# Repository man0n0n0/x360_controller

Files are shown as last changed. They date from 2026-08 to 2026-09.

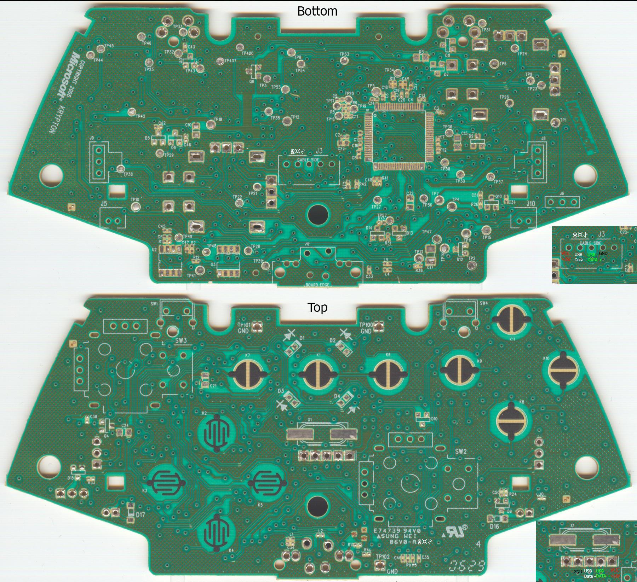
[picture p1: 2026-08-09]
hardware/F9HyhSM.jpg

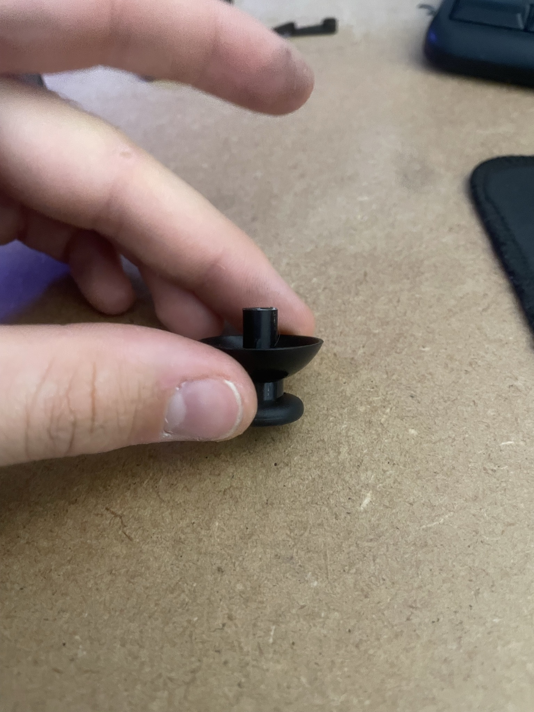
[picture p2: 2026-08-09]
img/IMG_0581.jpg

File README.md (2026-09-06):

# x360_controller

Manette Xbox 360 « jouée » par des servomoteurs : sticks, croix, boutons
colorés, gâchettes et moteurs de vibration sont actionnés mécaniquement
depuis un ESP32-C3, qui reçoit ses ordres d'un ordinateur hôte. Le but est
de rejouer une séquence de mouvements enregistrée, en synchronisation avec
une vidéo, pour une installation qui tourne sans opérateur.

## Contenu du dépôt

| Dossier / fichier | Contenu |
|---|---|
| `hardware/` | sources FreeCAD (`.FCStd`) et STL prêts à imprimer : coques, plaques, supports servo, mécanisme joystick PTFE, outil de perçage |
| `software/esp/` | firmware MicroPython de l'ESP32-C3 (`main_offline.py`, `main_wifi.py`, `boot.py`, `lib/servo.py`, `tools/servo_helper.py`) |
| `software/raspberrypi/` | maître Linux `control_host.py` (interface Tk + enregistreur) et séquence de test `button_test.json` |
| `software/raspberrypi/control_example/` | exemple d'installation : `record.py` (éditeur séquence/vidéo), `show.py` (lecture plein écran synchronisée), `caption.webm` |
| `img/` | photos de montage et schéma de câblage (`img/GPIO_servo`) |
| `FORMAT_JSON.md` | format des séquences |
| `notice.pdf` | notice d'assemblage illustrée |

## Architecture

```
hôte Linux  ──USB CDC (JSON par ligne)──▶  ESP32-C3  ──PWM/RMT──▶  servos + L298N
control_host.py / show.py                  main_offline.py
```

Deux firmwares au choix, couche de contrôle identique :

- **`main_offline.py`** (recommandé) — pilotage par USB série natif. Une
  ligne = un objet JSON. Pas de radio, latence limitée par le rafraîchissement
  servo à 50 Hz.
- **`main_wifi.py`** — point d'accès Wi-Fi + WebSocket et interface web
  embarquée. Pratique sans ordinateur, plus lent.

`boot.py` importe `main` : renommer ou adapter l'import selon le firmware
retenu. Appuyer sur **BOOT** au démarrage annule le lancement automatique et
donne accès au REPL (Thonny).

## Câblage (ESP32-C3 SuperMini)

| GPIO | Fonction |
|---|---|
| 0 / 1 | stick gauche X / Y |
| 2 / 3 | stick droit X / Y |
| 20 | croix directionnelle (4 directions) |
| 21 | boutons colorés (A/B/X/Y) |
| 4 / 10 | gâchettes LT / RT — pilotées par **RMT**, les 6 canaux LEDC étant déjà pris |
| 5 / 6 | L298N IN1 / IN2 — moteur de vibration A |
| 7 / 8 | L298N IN3 / IN4 — moteur B ; GPIO8 est aussi la LED intégrée |
| 9 | bouton BOOT — bascule le mode calibration |

Les cavaliers ENA/ENB du L298N restent en place (enable câblé HIGH) ; la
vitesse est modulée sur les broches IN.

## Mise en route

```bash
# hôte
pip install pyserial              # + pygame et ffmpeg pour control_example/
python3 software/raspberrypi/control_host.py /dev/ttyACM0
```

- **Mode calibration** — appui sur BOOT, LED bleue allumée : tous les servos
  se placent en position de montage. C'est dans cet état qu'on installe les
  pièces mécaniques (voir la notice).
- **Failsafe** — sans message pendant 1,5 s, l'ESP32 remet toutes les sorties
  à zéro. L'hôte envoie `{"hb": 1}` quelques fois par seconde pendant les
  silences.

## Séquences

`control_host.py` enregistre et rejoue les séquences ; dans
`control_example/`, `record.py` permet de composer une séquence face à une
vidéo et `show.py` diffuse vidéo + séquence en plein écran.

### Format JSON

Un fichier de séquence est du JSON ordinaire, versionné et modifiable à la
main :

```json
{
  "version": 1,
  "channels": ["joyL", "joyR", "trigL", "trigR",
               "motorA", "motorB", "button", "arrow"],
  "duration": 29.2813,
  "frames": [
    [2.0284, {"arrow": "up"}],
    [2.4451, {"arrow": null}],
    [3.1761, {"arrow": "right", "trigL": 0.5}]
  ]
}
```

Chaque entrée de `frames` est une paire `[temps, changements]` : le temps en
secondes depuis le début, et **uniquement les canaux qui changent** à cet
instant. On enregistre des différences, pas l'état complet — un canal absent
garde sa valeur précédente. Les entrées doivent être triées par temps
croissant.

| Canal | Valeur | Signification |
|---|---|---|
| `joyL`, `joyR` | `[x, y]`, de `-1.0` à `1.0` | sticks gauche et droit (`x` négatif vers la gauche, `y` négatif vers le haut) |
| `trigL`, `trigR` | `0.0` à `1.0` | gâchettes LT et RT (`0.0` = relâchée) |
| `motorA`, `motorB` | `0.0` à `1.0` | intensité des moteurs de vibration |
| `button` | `"A"`, `"B"`, `"X"`, `"Y"` ou `null` | bouton maintenu ; `null` = relâché |
| `arrow` | `"left"`, `"up"`, `"down"`, `"right"` ou `null` | croix directionnelle |

`button` et `arrow` ne sont pas des impulsions : ils restent actifs jusqu'à ce
qu'on les remette à `null`. Un appui s'écrit donc toujours en deux entrées, et
il est prudent de terminer une séquence en remettant tous les canaux au
neutre.

### Envoi par USB

L'ESP32 attend **un objet JSON par ligne**, terminé par `\n`, avec exactement
les clés des `frames` : rejouer une séquence revient à réémettre chaque entrée
au bon moment. Quelques commandes s'y ajoutent :

| Envoyé | Effet |
|---|---|
| `{"stop": 1}` | remet immédiatement toutes les sorties à zéro |
| `{"ping": 1}` | l'ESP32 répond `{"ev": "pong"}` |
| `{"get": 1}` | l'ESP32 renvoie son état complet |
| `{"hb": 1}` | battement de cœur, sans autre effet |

Détail complet, exemple de lecteur en Python et messages émis par la carte
dans [`FORMAT_JSON.md`](FORMAT_JSON.md).

## Assemblage

Voir `notice.pdf` : inserts à chaud et aimants, pose des servos, câblage
GPIO, montage des guignols, tube PTFE des joysticks, gâchettes récupérées sur
la manette d'origine, puis réglage des hauteurs pour éviter les frottements.

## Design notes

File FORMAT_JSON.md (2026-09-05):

# Format des séquences JSON

Une séquence décrit les mouvements de la manette dans le temps. Le même
fichier est utilisé par `record.py` (écriture), `show.py` et
`control_host.py` (lecture) 

## Structure

```json
{
  "version": 1,
  "channels": ["joyL", "joyR", "trigL", "trigR",
               "motorA", "motorB", "button", "arrow"],
  "duration": 29.2813,
  "frames": [
    [2.0284, {"arrow": "up"}],
    [2.4451, {"arrow": null}],
    [3.1761, {"arrow": "right", "trigL": 0.5}]
  ]
}
```

| Clé | Rôle |
|---|---|
| `version` | version du format, toujours `1` |
| `channels` | liste des canaux existants, à titre informatif |
| `duration` | horodatage de la dernière image, en secondes |
| `frames` | les événements, dans l'ordre chronologique |

## Les `frames`

Chaque entrée est une paire `[temps, changements]` :

- **temps** — secondes depuis le début, nombre décimal ;
- **changements** — uniquement les canaux qui *changent* à cet instant.

C'est le point essentiel : on enregistre des **différences**, pas l'état
complet. Un canal absent d'une entrée garde la valeur qu'il avait avant.
Pour connaître l'état à un instant donné, on part de la position neutre
et on applique dans l'ordre toutes les entrées jusqu'à ce moment.

Un fichier reste donc court et lisible : une séquence où seul le stick
gauche bouge ne contient que des lignes `joyL`.

## Les canaux

| Canal | Valeur | Signification |
|---|---|---|
| `joyL`, `joyR` | `[x, y]`, chacun de `-1.0` à `1.0` | sticks gauche et droit |
| `trigL`, `trigR` | `0.0` à `1.0` | gâchettes LT et RT (`0.0` = relâchée) |
| `motorA`, `motorB` | `0.0` à `1.0` | intensité des moteurs de vibration |
| `button` | `"A"`, `"B"`, `"X"`, `"Y"` ou `null` | bouton maintenu ; `null` = relâché |
| `arrow` | `"left"`, `"up"`, `"down"`, `"right"` ou `null` | croix directionnelle (4 directions) |

Pour `joyL` / `joyR` : `x` négatif vers la gauche, `y` négatif vers le
haut.

## Appuis et relâchements

`button` et `arrow` ne sont pas des impulsions : ils restent actifs
jusqu'à ce qu'on les remette à `null`. Un appui s'écrit donc toujours en
deux entrées.

```json
[2.03, {"arrow": "up"}],
[2.45, {"arrow": null}]
```

Sans la deuxième ligne, le servomoteur resterait appuyé sur la touche
jusqu'à la fin de la séquence.

## Règles à respecter

- Les entrées doivent être **triées par temps croissant**.
- Les valeurs sont bornées ; au-delà, l'ESP32 les ramène dans l'intervalle.
- Un fichier peut être modifié à la main : c'est du JSON ordinaire.
- Il est prudent de terminer une séquence en remettant tout au neutre,
  pour ne pas laisser un moteur ou une gâchette engagé.

```json
[29.28, {"joyL": [0, 0], "joyR": [0, 0], "trigL": 0.0, "trigR": 0.0,
         "motorA": 0.0, "motorB": 0.0, "button": null, "arrow": null}]
```

## Envoyer une séquence par USB

L'ESP32 attend **un objet JSON par ligne**, terminé par `\n`. Les clés
sont exactement celles des `frames` : il suffit donc de réécrire chaque
entrée telle quelle, au bon moment.

Le débit (`115200`) est une formalité : le port est un USB CDC natif, pas
une liaison série derrière une puce d'adaptation, et les données passent
à la vitesse de l'USB quelle que soit la valeur indiquée.

```python
#!/usr/bin/env python3
"""Rejoue une séquence sur la manette, via USB."""

import json, time, serial

PORT = "/dev/ttyACM0"
SEQUENCE = "show.json"

NEUTRE = {"joyL": [0, 0], "joyR": [0, 0], "trigL": 0.0, "trigR": 0.0,
          "motorA": 0.0, "motorB": 0.0, "button": None, "arrow": None}

frames = json.load(open(SEQUENCE))["frames"]
ser = serial.Serial(PORT, 115200, timeout=0.1)

def envoyer(objet):
    ser.write((json.dumps(objet) + "\n").encode())

try:
    depart = time.monotonic()
    for t, changements in frames:
        # On attend l'horodatage absolu de l'entrée, et non la durée
        # écoulée depuis la précédente : additionner les écarts ferait
        # dériver la séquence sur la longueur.
        reste = t - (time.monotonic() - depart)
        while reste > 0:
            time.sleep(min(reste, 0.5))
            envoyer({"hb": 1})     # voir la sécurité ci-dessous
            reste = t - (time.monotonic() - depart)
        envoyer(changements)
finally:
    envoyer({"stop": 1})           # remet tout au neutre
    ser.close()
```

### Sécurité : le battement de cœur

Si l'ESP32 ne reçoit rien pendant **1,5 seconde**, il remet toutes les
sorties à zéro. C'est volontaire : un ordinateur qui plante ne doit pas
laisser une gâchette enfoncée sur la manette.

Une séquence peut très bien rester silencieuse plusieurs secondes entre
deux mouvements ; d'où le `{"hb": 1}` envoyé pendant les attentes, qui
n'a aucun effet sinon celui de signaler que le maître est toujours là.

### Autres commandes utiles

| Envoyé | Effet |
|---|---|
| `{"stop": 1}` | remet immédiatement toutes les sorties à zéro |
| `{"ping": 1}` | l'ESP32 répond `{"ev": "pong"}` |
| `{"get": 1}` | l'ESP32 renvoie son état complet |
| `{"hb": 1}` | battement de cœur, sans autre effet |

L'ESP32 émet aussi de lui-même `{"ev": "calib", "on": true}` quand on
appuie sur le bouton BOOT, et `{"ev": "failsafe"}` s'il a coupé les
sorties faute de nouvelles. Il n'est pas obligatoire de lire ces
messages, mais il faut vider le port de temps en temps, sinon les
écritures de la carte finissent par se bloquer.

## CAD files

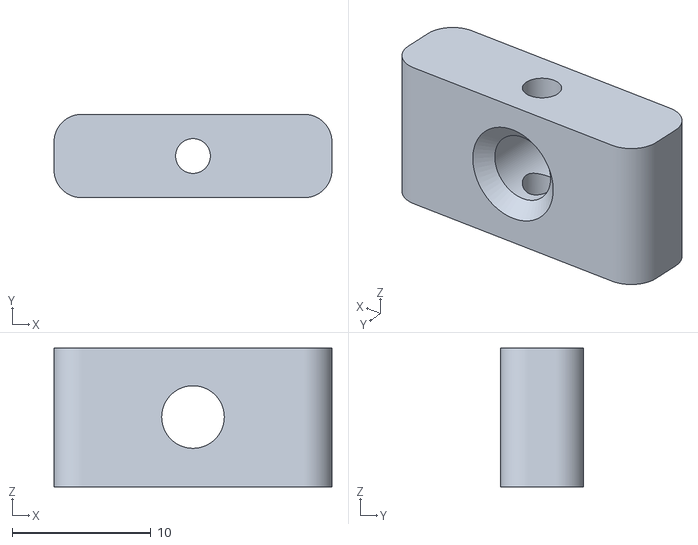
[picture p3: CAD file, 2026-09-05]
hardware/automated_joycstick-piercing_tool(1x).stl
20.0 x 6.00 x 10.0

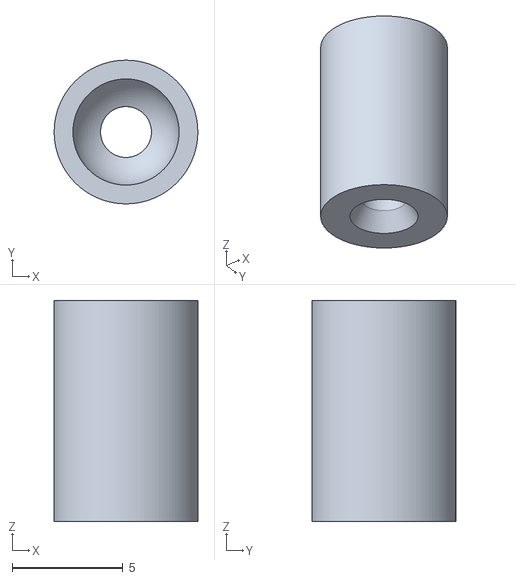
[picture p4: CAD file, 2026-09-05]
hardware/servo_button_control-button_extensions(4x).stl
6.50 x 6.50 x 10.0

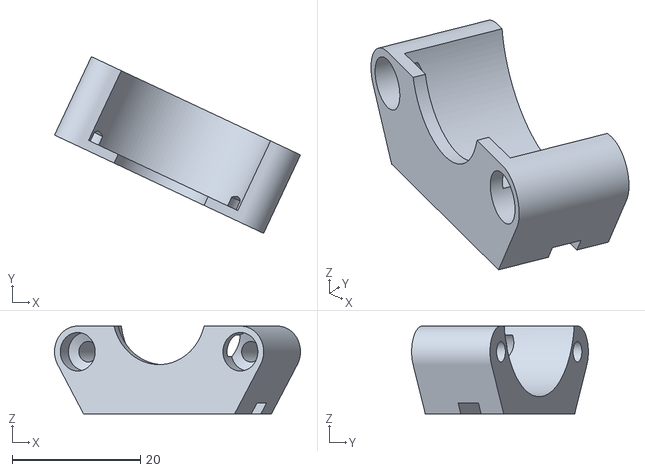
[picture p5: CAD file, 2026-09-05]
hardware/custom_controller-vibrator_bracket(2x).stl
38.3 x 27.5 x 13.7

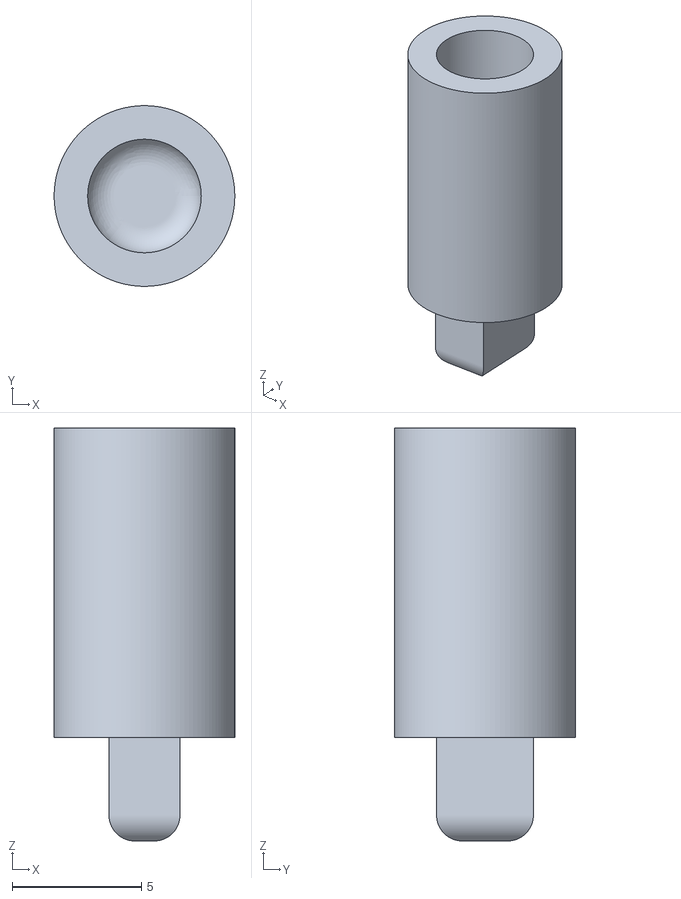
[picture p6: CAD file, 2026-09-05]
hardware/automated_joycstick-tip(x2).stl
7.00 x 7.00 x 16.0

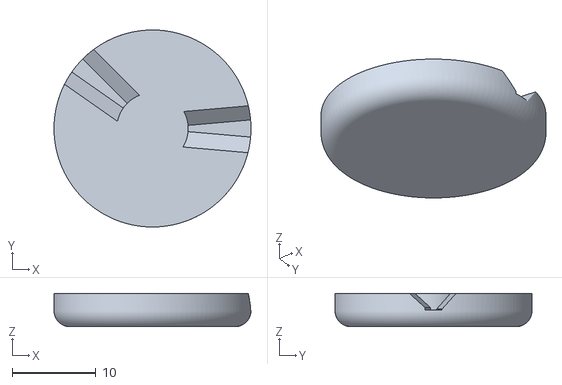
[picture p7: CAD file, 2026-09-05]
hardware/servo_button_control-base_arrow(1x).stl
23.6 x 23.6 x 4.00

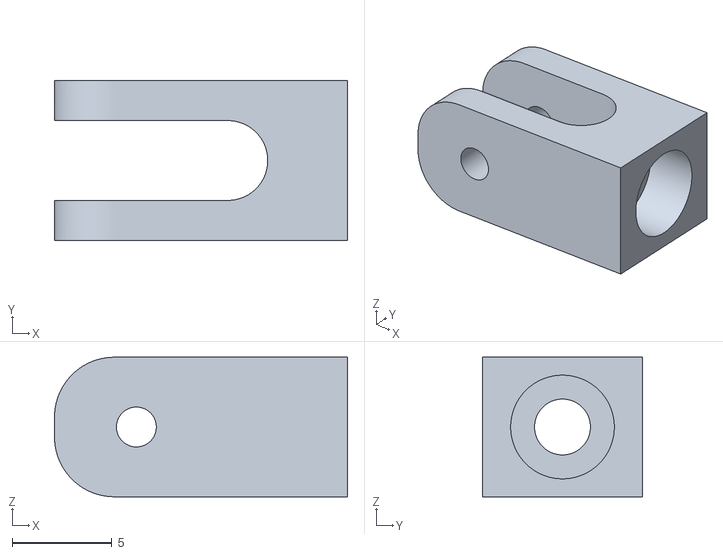
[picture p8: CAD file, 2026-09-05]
hardware/automated_joycstick-x(x2).stl
14.7 x 8.00 x 7.00

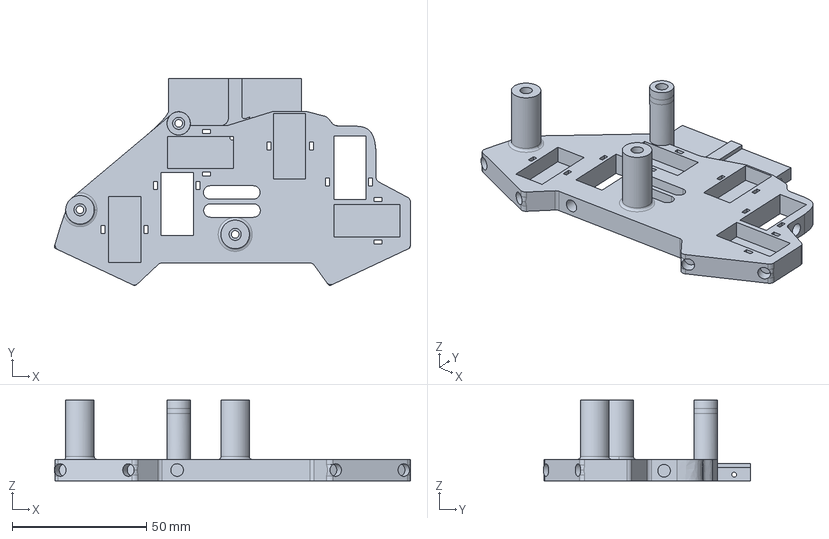
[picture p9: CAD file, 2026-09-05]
hardware/custom_controller.FCStd
132.5 x 77.2 x 30.0 mm

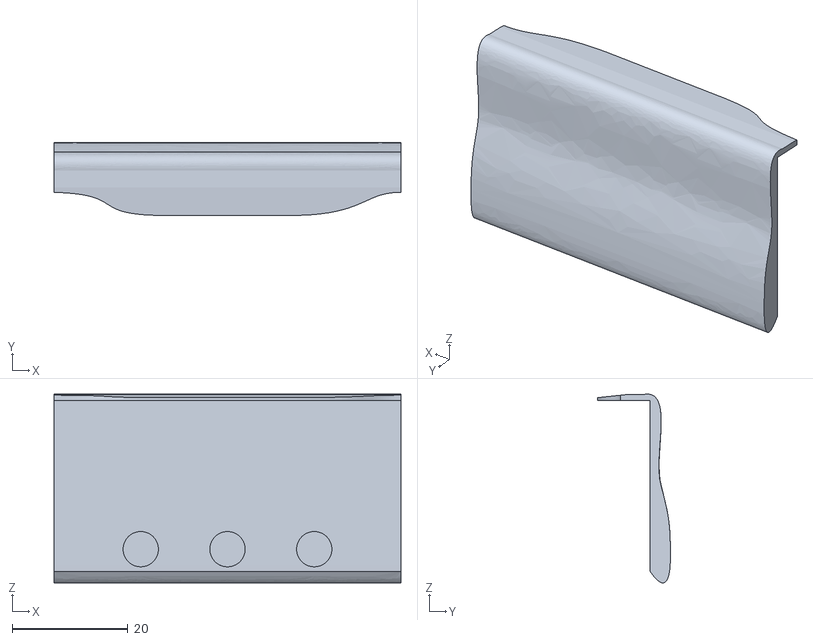
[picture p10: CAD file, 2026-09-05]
hardware/custom_controller-front_casing(1x).stl
60.0 x 12.6 x 32.7

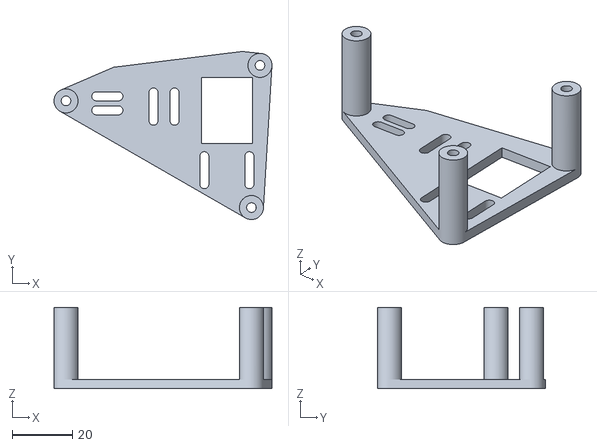
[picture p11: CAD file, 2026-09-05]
hardware/custom_controller-back_plate(1x).stl
72.6 x 56.0 x 27.0

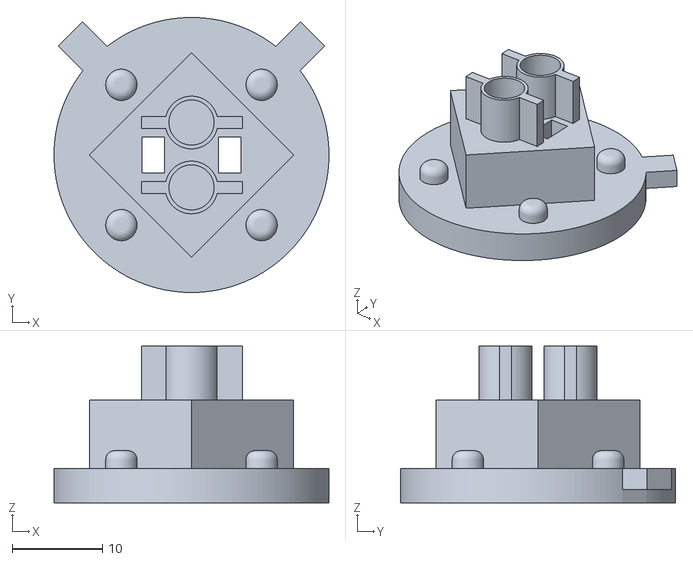
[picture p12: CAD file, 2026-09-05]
hardware/servo_button_control-arrow_plate(1x).stl
30.5 x 30.5 x 17.4

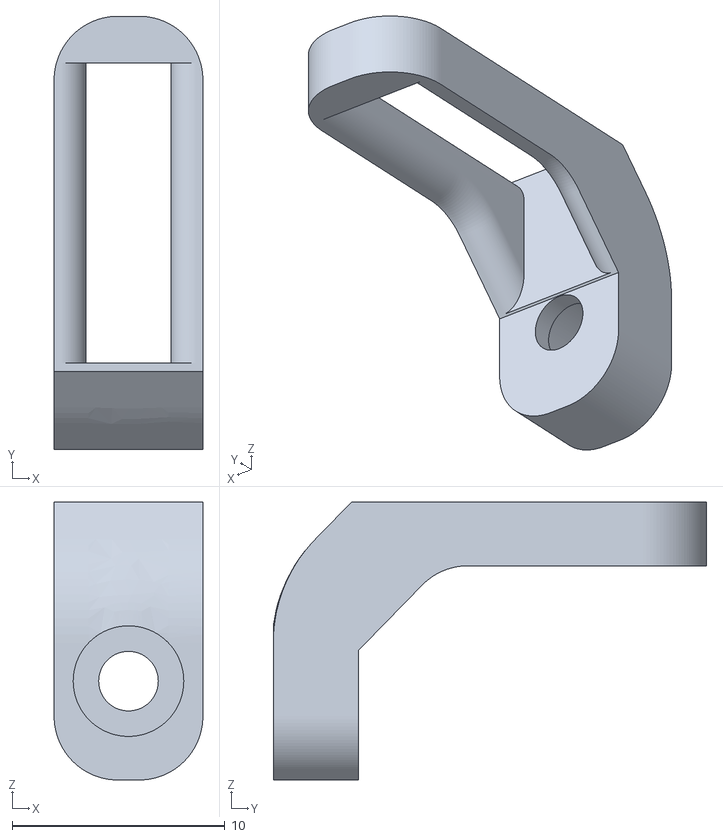
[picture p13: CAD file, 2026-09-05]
hardware/automated_joycstick-y(x2).stl
7.00 x 20.4 x 13.1

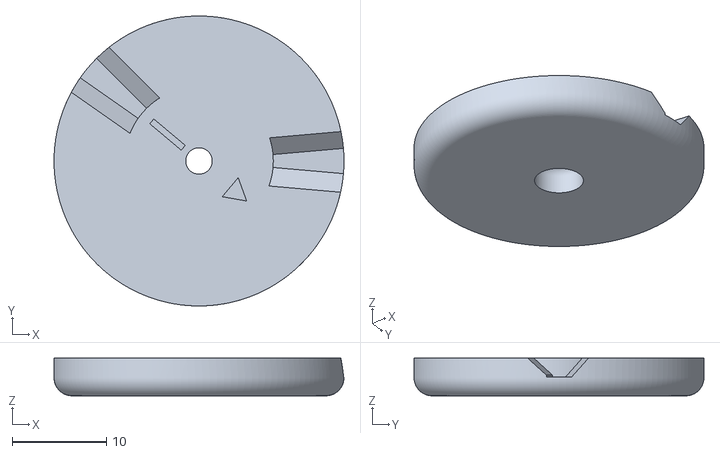
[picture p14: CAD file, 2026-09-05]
hardware/servo_button_control-base_screw_ptfe(1x).stl
30.8 x 30.8 x 4.00

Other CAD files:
hardware/automated_joycstick.FCStd
hardware/custom_controller-plate(1x).stl
hardware/servo_button_control.FCStd
hardware/servo_button_control-base_screw(1x).stl

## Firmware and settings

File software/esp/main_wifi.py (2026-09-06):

"""Ghost-player controller — ESP32-C3 / MicroPython (low-latency revision)
--------------------------------------------------------------------
Change from previous version: the browser-to-ESP32 control channel now
uses a persistent WebSocket instead of one HTTP POST per input event.

Why this matters for latency:
  - Each `fetch()` POST opened a *new* TCP connection: SYN / SYN-ACK / ACK
    handshake, then request, then response, then teardown — several
    round trips per single joystick sample.
  - A WebSocket performs that handshake exactly once at page load; every
    subsequent input is a single small frame over the already-open
    socket, with no reconnection cost.
  - MicroPython's asyncio scheduler is cooperative and single-core on
    the C3: a burst of simultaneous fetch() connections queues behind
    each other. A steady stream of frames on one connection avoids that
    contention.

Servo update rate is left at S = 0.015 s for the internal control
loops, but note the servo PWM signal itself runs at 50 Hz (one pulse
every 20 ms) — polling faster than ~20 ms cannot make the physical
servo respond any sooner, so further lowering S has no effect on
perceived latency once it is already below that figure.

PIN NOTES SPECIFIC TO ESP32-C3:
  - GPIO0 / GPIO2: strapping pins, safe to drive once booted.
  - GPIO20 / GPIO21: default UART0 RX/TX — confirm your board flashes
    over native USB (e.g. ESP32-C3 SuperMini) before reusing them.
  - GPIO11-17: reserved for SPI flash on most C3 modules, avoided here.
  - GPIO9: strapping pin, tied to the BOOT button and must read HIGH at
    reset — never driven, so no servo signal line can hold the board in
    the bootloader. It is read as an input to toggle calibration mode.
  - GPIO4 / GPIO10: the last two genuinely free pins on a SuperMini,
    now taken by the LT / RT trigger servos.
  - LEDC (PWM) peripheral: 6 channels total on the C3 — all six are
    already committed to the six servos above.

LT / RT TRIGGER SERVOS (GPIO4, GPIO10) — DRIVEN BY RMT, NOT LEDC:
  These are the seventh and eighth servos, and the LEDC peripheral has
  no channel left for them: machine.PWM() would simply fail. Software
  bit-banging them is also not an option — asyncio on MicroPython
  resolves to about a millisecond, while a servo's entire 500-2500 us
  pulse range is only two milliseconds wide, so the arm would twitch
  across its full travel.

  The C3's RMT peripheral solves this exactly: it has 2 TX channels,
  both unused, and it clocks pulses out in hardware. With clock_div=80
  against the 80 MHz APB clock one RMT tick equals one microsecond, so
  a servo frame is written literally as (pulse_us, 20000 - pulse_us)
  and looped. Timing quality is on par with LEDC; the only cost is that
  exactly two such outputs exist, which is all that is needed here.

L298N VIBRATION MOTOR DRIVER (GPIO5-8, wired to IN1-IN4):
  GPIO5-8 are wired to the four IN pins, not the two EN pins — ENA and
  ENB are left on the driver board's default jumpers, which bridge
  each enable line permanently HIGH. No rewiring is required for that:
  it is the factory-default state of an L298N breakout as long as the
  ENA/ENB jumpers were never removed.

  With EN held permanently HIGH, the standard technique for speed
  control directly on the IN pins is to PWM one IN pin of a motor's
  pair while holding its partner LOW: the H-bridge chops the supply
  at the PWM duty cycle exactly as if EN itself were being PWMed.
  Holding the partner HIGH instead would run the same trick in the
  opposite fixed direction — irrelevant here since a vibration motor
  has no meaningful "reverse".
      GPIO5 -> IN1  (motor A intensity, PWM)
      GPIO6 -> IN2  (motor A, held LOW, fixed)
      GPIO7 -> IN3  (motor B intensity, PWM)
      GPIO8 -> IN4  (motor B, held LOW, fixed)

  IMPORTANT HARDWARE CONSTRAINT: the ESP32-C3's LEDC peripheral is
  already at its 6-channel ceiling (the six servos). The two PWMed IN
  pins therefore cannot use machine.PWM — there is no 7th or 8th
  hardware channel available. Motor intensity is instead driven by a
  software (bit-banged) PWM implemented below with asyncio. This is
  coarser and jitterier than LEDC, but adequate for a DC vibration
  motor's average voltage, which the motor's own mechanical inertia
  low-pass-filters.

FIRMWARE REQUIREMENT: machine.PWM.duty_ns() needs MicroPython >=1.20.
"""

import network
import asyncio
import random
import ujson
import ubinascii
import uhashlib
from machine import Pin, PWM
from esp32 import RMT


# ---------------------------------------------------------------------
# Servo driver (machine.PWM wrapper — 50 Hz, pulse width in microseconds)
# ---------------------------------------------------------------------
class Servo:
    def __init__(self, pin, freq=50, min_us=500, max_us=2500, angle_range=180):
        self._pwm = PWM(Pin(pin), freq=freq)
        self._min_us = min_us
        self._max_us = max_us
        self._angle_range = angle_range

    def move(self, angle):
        angle = max(0, min(self._angle_range, angle))
        us = self._min_us + (self._max_us - self._min_us) * angle / self._angle_range
        self._pwm.duty_ns(int(us * 1000))

    def deinit(self):
        self._pwm.deinit()


# ---------------------------------------------------------------------
# RMT servo driver (same 50 Hz / microsecond-pulse contract as Servo
# above, but clocked out by the RMT peripheral instead of LEDC — see
# the docstring for why the trigger servos cannot use machine.PWM).
#
# clock_div=80 divides the 80 MHz APB clock down to 1 MHz, so one RMT
# tick is one microsecond and pulse widths are written directly in the
# units the servo datasheet uses.
# ---------------------------------------------------------------------
class RMTServo:
    def __init__(self, channel, pin, home=0, min_us=500, max_us=2500,
                 angle_range=180, period_us=20000):
        self._rmt = RMT(channel, pin=Pin(pin), clock_div=80)
        self._min_us = min_us
        self._max_us = max_us
        self._angle_range = angle_range
        self._period_us = period_us
        self._last_us = None
        # Looping makes the peripheral repeat the two-entry sequence
        # forever without further CPU involvement — the servo sees a
        # continuous 50 Hz frame even while the control loop is idle.
        self._rmt.loop(True)
        self.move(home)

    def move(self, angle):
        angle = max(0, min(self._angle_range, angle))
        us = int(self._min_us + (self._max_us - self._min_us) * angle / self._angle_range)
        # Rewriting an unchanged waveform would restart the loop and
        # emit a truncated pulse, so only push real changes.
        if us == self._last_us:
            return
        self._last_us = us
        # (high_ticks, low_ticks), second argument being the initial
        # output level. It must be passed positionally: the esp32 RMT
        # methods are native and reject keyword arguments.
        self._rmt.write_pulses((us, self._period_us - us), 1)

    def deinit(self):
        self._rmt.loop(False)
        self._rmt.deinit()


# ---------------------------------------------------------------------
# Software PWM (for the two L298N enable pins — no hardware LEDC
# channels remain, since the six servos above already use all six).
# Bit-banged via asyncio at a modest frequency; sufficient for driving
# a DC vibration motor's average voltage, not for anything requiring
# clean, precise pulse timing.
# ---------------------------------------------------------------------
class SoftPWM:
    def __init__(self, pin, freq=200):
        self._pin = Pin(pin, Pin.OUT)
        self._pin.value(0)
        self._period = 1.0 / freq
        self.duty = 0.0   # 0.0 .. 1.0, updated externally, read by run()

    async def run(self):
        while True:
            d = self.duty
            if d <= 0.0:
                self._pin.value(0)
                await asyncio.sleep(self._period)
            elif d >= 1.0:
                self._pin.value(1)
                await asyncio.sleep(self._period)
            else:
                self._pin.value(1)
                await asyncio.sleep(self._period * d)
                self._pin.value(0)
                await asyncio.sleep(self._period * (1.0 - d))


# ---------------------------------------------------------------------
# Hardware map
# ---------------------------------------------------------------------
colored = Servo(pin=21)
arrow_servo = Servo(pin=20)
servoxl = Servo(pin=0)
servoyl = Servo(pin=1)
servoxr = Servo(pin=2)
servoyr = Servo(pin=3)

# MicroPython hands one RMT channel to machine.bitstream (the neopixel
# timing generator) at startup, which on the C3 leaves only one of the
# two TX channels free — not enough for both triggers. Passing None
# releases it and falls machine.bitstream back to bit-banging; nothing
# in this project drives addressable LEDs, so that costs us nothing.
RMT.bitstream_channel(None)

# LT / RT triggers — RMT TX channels 0 and 1, the only two the C3 has.
# The two servos face each other across the controller, so they sweep in
# opposite directions: LT rests at 0 deg and counts up, RT rests at
# 180 deg and counts down. Both cover the same 60 deg of travel.
trigger_l = RMTServo(channel=0, pin=4, home=0)
trigger_r = RMTServo(channel=1, pin=10, home=180)

# L298N vibration motor driver — wired to IN1-IN4 (ENA/ENB left on
# their default jumpers, permanently HIGH). See docstring for the
# IN-pin PWM-chopping technique this relies on.
motorA_dir = Pin(6, Pin.OUT)   # IN2
motorA_dir.value(0)            # held low, fixed
motorA_en = SoftPWM(pin=5)     # IN1 — intensity (software PWM)

motorB_dir = Pin(8, Pin.OUT)   # IN4 — also the board's built-in LED
motorB_en = SoftPWM(pin=7)     # IN3


def status_led(on):
    # GPIO8 does double duty: it is IN4 on the driver and the SuperMini's
    # built-in LED, which is active LOW. Lighting it for calibration mode
    # therefore leaves IN4 HIGH for the whole of normal operation, which
    # reverses motor B and inverts what a duty on IN3 means. motor_b_task
    # compensates for the duty; the reversal is harmless on a vibration
    # motor, which buzzes the same either way.
    motorB_dir.value(0 if on else 1)


status_led(False)              # boot straight into the non-calibrating state
motorB_en.duty = 1.0           # IN4 is HIGH at rest; match it on IN3 to brake,
                               # or the motor runs flat out until motor_b_task
                               # gets its first cycle in.

# BOOT button (GPIO9). Safe to read as an input — the strapping
# constraint is about what drives the pin at reset, and the button's
# own external pull-up already holds it HIGH there. Active LOW.
boot_button = Pin(9, Pin.IN, Pin.PULL_UP)

centerxl, centeryl = 90, 90
centerxr, centeryr = 90, 90
radius = 9      # max servo travel, in degrees, representing full joystick deflection
trigger_travel = 35  # degrees swept from released (0) to fully pulled (1.0)
trigger_l_rest = trigger_travel    # LT sweeps to 0
trigger_r_rest = 180 - trigger_travel  # RT is mirrored: 180 -> 120
S = 0.015       # internal control-loop interval, in seconds — see note above on the 20 ms PWM floor

buttons = {"A": 90, "B": 170, "Y": 40, "X": 140}
arrows = {"down": 40, "right": 140, "up": 90, "left": 180}

# ---------------------------------------------------------------------
# Calibration mode
#
# Pressing the BOOT button parks every servo at a known angle and holds
# it there, so the arms can be unscrewed and reseated against the real
# controller without the control loops fighting the adjustment. A second
# press hands control back to the browser.
#
# These are the angles the mechanism should be *assembled* at, which is
# not always the same as the angle a control loop treats as neutral —
# the triggers, for instance, are adjusted at their fully released
# position rather than mid-travel. Edit the values here to re-aim the
# rig; nothing else needs changing.
# ---------------------------------------------------------------------
CALIBRATION = {
    "colored": 90,               # coloured-button servo, off every button
    "arrow": 90,                 # d-pad servo, off every one of the four directions
    "joyL_x": centerxl,          # left stick, both axes centred
    "joyL_y": centeryl,
    "joyR_x": centerxr,          # right stick, both axes centred
    "joyR_y": centeryr,
    "trigL": trigger_l_rest+trigger_travel,     # triggers fully truigered
    "trigR": trigger_r_rest-trigger_travel,
}

# Name -> servo object, so CALIBRATION above stays a plain table of
# angles that can be edited without touching any wiring.
SERVOS = {
    "colored": colored,
    "arrow": arrow_servo,
    "joyL_x": servoxl,
    "joyL_y": servoyl,
    "joyR_x": servoxr,
    "joyR_y": servoyr,
    "trigL": trigger_l,
    "trigR": trigger_r,
}

state = {
    "button": None,
    "arrow": None,
    "joyL": (0.0, 0.0),
    "joyR": (0.0, 0.0),
    "motorA": 0.0,        # vibration intensity, 0.0 .. 1.0
    "motorB": 0.0,
    "trigL": 0.0,         # analogue trigger travel, 0.0 (released) .. 1.0 (fully pulled)
    "trigR": 0.0,
    "calibrating": False, # True while the BOOT button has parked the servos
}


def clamp(v, lo, hi):
    return max(lo, min(hi, v))


# ---------------------------------------------------------------------
# Control coroutines
# ---------------------------------------------------------------------
async def button_task():
    # Edge-triggered, not continuous: the servo only issues a new move()
    # when state["button"] *changes* value (press -> exact target angle,
    # release -> a single +-10 deg nudge from wherever it already is).
    # Re-applying the same target every poll cycle would be harmless for
    # the "pressed" case but wrong for "released": jitter must happen
    # once per release, not accumulate every S seconds.
    prev = "__unset__"          # sentinel so the very first cycle also triggers
    current_angle = 90          # assumed neutral position before any press
    while True:
        if state["calibrating"]:
            # Resetting the sentinel means the current button state is
            # re-applied on the way out, rather than the servo silently
            # staying at its calibration angle until the next press.
            prev = "__unset__"
            # The servo is physically at its calibration angle now, so
            # the release-nudge below must be measured from there and
            # not from wherever it happened to be before the press.
            current_angle = CALIBRATION["colored"]
            await asyncio.sleep(S)
            continue
        b = state["button"]
        if b != prev:
            if b in buttons:
                current_angle = buttons[b]
            else:
                # released: move a small directio nto de-engage the button
                current_angle = current_angle + 25 if current_angle < 90 else current_angle -25
            colored.move(current_angle)
            prev = b
        await asyncio.sleep(S)


async def arrow_task():
    prev = "__unset__"          # sentinel so the very first cycle also triggers
    current_angle = 65          # assumed neutral position before any press
    while True:
        if state["calibrating"]:
            prev = "__unset__"          # see button_task
            current_angle = CALIBRATION["arrow"]
            await asyncio.sleep(S)
            continue
        a = state["arrow"]
        if a != prev:
            if a in arrows:
                current_angle = arrows[a]
            else:
                # released: move a small direction to de-engage the arrow.
                # 25 deg lands midway between two of the four positions
                # (40 -> 65, 90 -> 65, 140 -> 115, 180 -> 155) so no
                # neighbouring direction is pressed on the way out.
                current_angle = current_angle + 25 if current_angle < 90 else current_angle - 25
            arrow_servo.move(current_angle)
            prev = a
        await asyncio.sleep(S)


async def joystick_l_task():
    while True:
        if state["calibrating"]:
            await asyncio.sleep(S)
            continue
        x, y = state["joyL"]
        # Y is negated on both sticks, and X on the right stick only, to
        # match how the servo arms are mounted against the target sticks.
        servoxl.move(clamp(centerxl + x * radius, 0, 180))
        servoyl.move(clamp(centeryl - y * radius, 0, 180))
        await asyncio.sleep(S)


async def joystick_r_task():
    while True:
        if state["calibrating"]:
            await asyncio.sleep(S)
            continue
        x, y = state["joyR"]
        servoxr.move(clamp(centerxr - x * radius, 0, 180))
        servoyr.move(clamp(centeryr - y * radius, 0, 180))
        await asyncio.sleep(S)


async def trigger_task():
    # Both triggers share one coroutine: they are analogue like the
    # joysticks (continuously re-applied, not edge-triggered), but
    # RMTServo.move() already suppresses redundant writes, so polling
    # them together costs nothing when nothing is moving.
    while True:
        if state["calibrating"]:
            await asyncio.sleep(S)
            continue
        trigger_l.move(trigger_l_rest + state["trigL"] * trigger_travel)
        trigger_r.move(trigger_r_rest - state["trigR"] * trigger_travel)
        await asyncio.sleep(S)


async def motor_a_task():
    # Silenced during calibration: a buzzing rig is no help when you are
    # trying to seat a servo horn by hand.
    while True:
        motorA_en.duty = 0.0 if state["calibrating"] else state["motorA"]
        await asyncio.sleep(S)


async def motor_b_task():
    while True:
        # The L298N drives the motor whenever IN3 and IN4 differ. IN4 is
        # LOW only while calibrating (see status_led), so the duty that
        # means "still" flips with the mode. Both branches below hold
        # state["motorB"] to the same meaning: 0.0 still, 1.0 full.
        if state["calibrating"]:
            motorB_en.duty = 0.0
        else:
            motorB_en.duty = 1.0 - state["motorB"]
        await asyncio.sleep(S)


async def boot_button_task():
    # Toggle calibration mode on each press of the BOOT button.
    #
    # While calibrating this keeps re-applying the table every cycle
    # rather than issuing one move on entry. That costs nothing (the
    # servo drivers are just rewriting an identical pulse width) and it
    # removes a race: the control loops check the flag on their own S
    # interval, so one of them can still push a stale angle out just
    # after the mode changes. Continuously re-asserting wins that race.
    prev = 1                       # active low, released == 1
    while True:
        v = boot_button.value()
        if prev == 1 and v == 0:                  # falling edge = press
            state["calibrating"] = not state["calibrating"]
            status_led(state["calibrating"])
            print("calibration mode:", "ON" if state["calibrating"] else "OFF")
            await asyncio.sleep(0.2)              # ride out contact bounce
            v = boot_button.value()
        prev = v

        if state["calibrating"]:
            for name, angle in CALIBRATION.items():
                SERVOS[name].move(angle)

        await asyncio.sleep(0.02)


# ---------------------------------------------------------------------
# Wi-Fi access point
# ---------------------------------------------------------------------
def start_ap(ssid="ghost-player", password="cognitivsculptur"):
    ap = network.WLAN(network.AP_IF)
    ap.active(True)
    ap.config(essid=ssid, password=password, authmode=network.AUTH_WPA2_PSK)
    while not ap.active():
        pass
    return ap


# ---------------------------------------------------------------------
# Minimal WebSocket server (RFC 6455 subset: text frames only, no ping/
# pong, no fragmentation handling — sufficient for short JSON control
# messages on a trusted local AP).
# ---------------------------------------------------------------------
WS_MAGIC = "258EAFA5-E914-47DA-95CA-C5AB0DC85B11"


def ws_accept_key(client_key):
    digest = uhashlib.sha1((client_key + WS_MAGIC).encode()).digest()
    return ubinascii.b2a_base64(digest).decode().strip()


async def ws_read_frame(reader):
    b1 = await reader.readexactly(1)
    b2 = await reader.readexactly(1)
    opcode = b1[0] & 0x0F
    masked = b2[0] & 0x80
    length = b2[0] & 0x7F
    if length == 126:
        length = int.from_bytes(await reader.readexactly(2), "big")
    elif length == 127:
        length = int.from_bytes(await reader.readexactly(8), "big")
    mask = await reader.readexactly(4) if masked else None
    data = await reader.readexactly(length) if length else b""
    if masked:
        data = bytes(b ^ mask[i % 4] for i, b in enumerate(data))
    return opcode, data


def ws_encode_text(msg):
    payload = msg.encode()
    n = len(payload)
    if n < 126:
        header = bytes([0x81, n])
    elif n < 65536:
        header = bytes([0x81, 126]) + n.to_bytes(2, "big")
    else:
        header = bytes([0x81, 127]) + n.to_bytes(8, "big")
    return header + payload
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

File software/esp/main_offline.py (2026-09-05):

"""Ghost-player controller — ESP32-C3 / MicroPython, USB-serial revision
--------------------------------------------------------------------
Offline twin of main.py. The control layer below is identical, line for
line: same servo drivers, same pins, same angles, same calibration mode
on the BOOT button. Only the transport differs — there is no Wi-Fi AP,
no HTTP server, no WebSocket and no embedded browser UI. A master
program on a Linux host drives the rig over the native USB CDC port
instead (see control_host.py).

WHY USB IS THE FASTER LINK, NOT THE SLOWER ONE:
  The Wi-Fi build spends most of its latency budget on radio, not on
  code — association, retries, and the AP's own beacon interval. Native
  USB CDC on the C3 has none of that: it is a 12 Mbit/s wired pipe with
  no contention, and a control frame is a few dozen bytes. The limiting
  factor becomes the 50 Hz servo refresh again, exactly as it should be.

  It also removes the single-core scheduler pressure described in
  main.py: no TCP stack, no socket accept loop, no per-connection
  buffers competing with the servo coroutines for the same core.

PROTOCOL — newline-delimited JSON, one object per line, both directions.
  Chosen over a packed binary format deliberately: at these rates the
  parsing cost is irrelevant, and being able to drive the rig by typing
  a line into a serial terminal is worth far more during bring-up than
  the bytes it saves.

  HOST -> DEVICE, every key optional, unknown keys ignored:
      {"joyL": [x, y]}      x, y in -1.0 .. 1.0
      {"joyR": [x, y]}
      {"trigL": f}          0.0 (released) .. 1.0 (fully pulled)
      {"trigR": f}
      {"motorA": f}         0.0 .. 1.0 vibration intensity
      {"motorB": f}
      {"button": "A"|"B"|"X"|"Y"|null}      null == released
      {"arrow": "left"|"up"|"right"|"down"|null}
      {"ping": 1}           -> device replies {"ev": "pong"}
      {"get": 1}            -> device replies with a full state dump
      {"stop": 1}           -> zero every output immediately
      {"hb": 1}             -> heartbeat, no reply (see failsafe below)

  DEVICE -> HOST:
      {"ev": "ready"}                  once, at startup
      {"ev": "calib", "on": true}      BOOT button toggled calibration
      {"ev": "pong"}
      {"ev": "state", ...}             full state dump, answer to "get"
      {"ev": "failsafe"}               link went quiet, outputs zeroed
      {"ev": "err", "msg": "..."}      unparseable line

FAILSAFE:
  A servo rig that keeps a trigger pulled because the host crashed is a
  physical problem, not a software one. If nothing arrives from the host
  for LINK_TIMEOUT_MS, every output is zeroed. The host is expected to
  send {"hb":1} a few times a second when it has nothing else to say —
  cheap insurance, since idle periods are otherwise indistinguishable
  from a dead master.

RUNNING IT:
  boot.py imports `main`, so this file does not start on its own. Either
  point boot.py at `main_offline` instead, or from the REPL:
      >>> import main_offline
  Ctrl-C still interrupts: the protocol is plain ASCII JSON and never
  contains a 0x03 byte, so there is no reason to disable the interrupt.

For the full pin rationale, the LEDC-versus-RMT explanation and the
L298N wiring notes, see the docstring of main.py — all of it applies
here unchanged.
"""

import sys
import select
import time
import asyncio
import ujson
from machine import Pin, PWM
from esp32 import RMT


# ---------------------------------------------------------------------
# Servo driver (machine.PWM wrapper — 50 Hz, pulse width in microseconds)
# ---------------------------------------------------------------------
class Servo:
    def __init__(self, pin, freq=50, min_us=500, max_us=2500, angle_range=180):
        self._pwm = PWM(Pin(pin), freq=freq)
        self._min_us = min_us
        self._max_us = max_us
        self._angle_range = angle_range

    def move(self, angle):
        angle = max(0, min(self._angle_range, angle))
        us = self._min_us + (self._max_us - self._min_us) * angle / self._angle_range
        self._pwm.duty_ns(int(us * 1000))

    def deinit(self):
        self._pwm.deinit()


# ---------------------------------------------------------------------
# RMT servo driver — see main.py for why the triggers cannot use LEDC.
# ---------------------------------------------------------------------
class RMTServo:
    def __init__(self, channel, pin, home=0, min_us=500, max_us=2500,
                 angle_range=180, period_us=20000):
        self._rmt = RMT(channel, pin=Pin(pin), clock_div=80)
        self._min_us = min_us
        self._max_us = max_us
        self._angle_range = angle_range
        self._period_us = period_us
        self._last_us = None
        self._rmt.loop(True)
        self.move(home)

    def move(self, angle):
        angle = max(0, min(self._angle_range, angle))
        us = int(self._min_us + (self._max_us - self._min_us) * angle / self._angle_range)
        if us == self._last_us:
            return
        self._last_us = us
        self._rmt.write_pulses((us, self._period_us - us), 1)

    def deinit(self):
        self._rmt.loop(False)
        self._rmt.deinit()


# ---------------------------------------------------------------------
# Software PWM for the two L298N intensity pins.
# ---------------------------------------------------------------------
class SoftPWM:
    def __init__(self, pin, freq=200):
        self._pin = Pin(pin, Pin.OUT)
        self._pin.value(0)
        self._period = 1.0 / freq
        self.duty = 0.0

    async def run(self):
        while True:
            d = self.duty
            if d <= 0.0:
                self._pin.value(0)
                await asyncio.sleep(self._period)
            elif d >= 1.0:
                self._pin.value(1)
                await asyncio.sleep(self._period)
            else:
                self._pin.value(1)
                await asyncio.sleep(self._period * d)
                self._pin.value(0)
                await asyncio.sleep(self._period * (1.0 - d))


# ---------------------------------------------------------------------
# Hardware map
# ---------------------------------------------------------------------
colored = Servo(pin=21)
arrow_servo = Servo(pin=20)
servoxl = Servo(pin=0)
servoyl = Servo(pin=1)
servoxr = Servo(pin=2)
servoyr = Servo(pin=3)

# machine.bitstream (the neopixel timing generator) claims one RMT
# channel at startup, leaving only one of the C3's two TX channels free.
# Releasing it falls bitstream back to bit-banging, which costs nothing
# here since no addressable LEDs are driven.
RMT.bitstream_channel(None)

trigger_l = RMTServo(channel=0, pin=4, home=0)
trigger_r = RMTServo(channel=1, pin=10, home=180)

motorA_dir = Pin(6, Pin.OUT)   # IN2
motorA_dir.value(0)
motorA_en = SoftPWM(pin=5)     # IN1 — intensity

motorB_dir = Pin(8, Pin.OUT)   # IN4 — also the board's built-in LED
motorB_en = SoftPWM(pin=7)     # IN3
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

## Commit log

2026-08-09 rev 1 : need to fix the coloured button friction and update the assembly guide
    [Xbox360kontrollstep242.stp, automated_joycstick-pin.stl, automated_joycstick.FCStd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]
2026-09-05 first rev done
    [Xbox360kontrollstep242.stp, automated_joycstick-piercing_tool(1x).stl, automated_joycstick-pin.stl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]
2026-09-06 Add gitignore, restore notice/control_example, refresh README
    Untrack venv, __pycache__ and FreeCAD .FCBak backups; update the README
    to match the current tree.
2026-10-27 Add main_offline_nomotors: USB-serial build with servos only
    Six LEDC servos, no RMT trigger servos and no L298N motors. Trigger and
    motor keys are still accepted by the protocol but ignored.
